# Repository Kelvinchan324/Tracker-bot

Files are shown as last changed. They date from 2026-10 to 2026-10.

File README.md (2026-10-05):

# Tracker Bot

## EVT-A.1 build and teaching manual (5 October 2026)

The implemented reference build is **XIAO ESP32-S3 Sense + two SG90 servos**
tracking a red marker. It is an untested hardware draft; it does not yet detect
people. The earlier product vision below describes future goals.

[Engineering manual](docs/engineering.md) · [BOM](hardware/BOM.md) ·
[Wiring schematic](hardware/schematic.svg) · [Placement drawing](mechanical/placement.svg) ·
[STEP draft](mechanical/layout-draft.step)

**Wiring revision:** EVT-A.1 uses TXU0102, not the old AHCT125. Read the
[power-cut and interlock guide](docs/power-and-interlock.md) and
[parametric mounting drafts](mechanical/README.md). Do not reuse the old pinout.

1. Read the wiring and power notes. Keep the camera USB and motor supplies separate;
   join ground. Wire GPIO1/D0 and GPIO2/D1 through the translator, GPIO3 to OE,
   and GPIO4 to the separate NC stop contact with its 3.3 V pull-up.
2. Install PlatformIO and run `cd firmware`, then `pio run -e xiao-sense`.
3. With horns removed and motor power off, connect USB and run
   `pio run -e xiao-sense --target upload`, then `pio device monitor`.
4. Boot should report motors DISARMED. Verify no PWM. Enable motor power, support
   the mechanism, close the stop contact, then enter `arm`; the last commanded
   position (initially centre) can cause movement. Release after a stop does not re-arm.
5. Try `target 0.2 0` in serial mode. Check direction and timeout before fitting
   the horns. `stop` holds position; `disarm` removes PWM. Use the physical cut if needed.
6. Enter `camera` and present one red marker. Remove it to check lost-target behaviour.
   Enter `serial` to return to manual target input. Use `status` for diagnostics.
7. Follow the four lessons in the engineering manual and save the measured results.

Read the [camera freshness and calibration lesson](docs/camera-calibration.md)
before marker tracking. Frame age is measured from capture start, not retrieval.
`status` reports the last frame classification, red sample/candidate/selected
counts and capture age. Two separate qualifying red regions now reject as
`ambiguous`; a unique region needs at least 20 connected samples. Touching objects
can still merge, and a lone distractor can still qualify—this is not identity tracking.
Fresh images without a unique marker stop incremental commands but hold PWM;
normal marker reacquisition remains automatic while camera mode is selected.
Camera-stream faults (missing/invalid/stale frames or age over 750 ms) now exit
camera mode. Fresh frames alone cannot restart it: inspect the fault, wait for
`camera_stream=live`, then send `camera` explicitly. This main-loop check is not
an independent watchdog or power cut. No encoder or obstruction sensor is
implemented, and physical stopping remains unvalidated.

Serial control now rejects malformed or unknown commands by stopping tracking
and leaving camera mode. Lines are limited to 96 ASCII bytes and must finish
within one second of their first processed byte. Rejected lines are discarded
through the next newline. Read the [serial controls lesson](docs/serial-controls.md)
before attaching scripts; stopping increments still holds PWM, not motor power.

PWM setup now uses the ESP32-S3's supported **14-bit, 50 Hz** configuration.
The earlier 16-bit request was rejected by the pinned driver despite compiling.
Both axes must report successful setup before `arm`; `status` includes `pwm_setup`.
Read the [PWM startup lesson](docs/pwm-startup.md) and measure the actual outputs
with motors unplugged. A successful driver return does not verify a waveform.

The CAD now includes [candidate moving carriers and joint-frame review](mechanical/carrier-review.md),
with a [labelled STEP-derived assembly review](mechanical/carrier-visual-review.png)
showing assumed actuator axes, camera envelope and unfinished horn connections,
not a finished pan/tilt mechanism. Run `python tools/build_engineering.py --cad`,
`python tools/build_mounts.py`, then `python tools/build_carriers.py` with CadQuery
2.8.0. The last script samples 25 nominal poses and reports envelope intrusion;
it does not certify continuous clearance or measured shaft/optical frames.
Actual motor travel, bracket fit, camera orientation, back-feed,
continuous current and tracking quality remain physical acceptance tests.

A compact, affordable pan-and-tilt camera that follows a selected person or
object using on-device computer vision.

Tracker Bot takes the core idea behind the larger
[YOLO Tracker](https://github.com/Kelvinchan324/YOLO_tracker) and explores how
to turn it into a smaller, quieter, lower-cost product for individual
customers. The proposed design uses an AI-capable ESP32 module for lightweight
tracking and two compact actuators for yaw and pitch.

> **Project status:** early product concept and feasibility study. The camera,
> ESP32 module, actuators, power system, enclosure, and retail specifications
> have not been finalized.

## Product vision

- Small enough for a desk, shelf, tripod, or portable demonstration setup.
- Lower-cost alternative to a Raspberry Pi and full-size smart-servo tracker.
- On-device tracking with low latency and no mandatory cloud connection.
- Simple setup for non-technical B2C customers.
- Smooth, quiet motion suitable for home video, calls, content creation, and
  hobby use.
- Modular mechanical design so the actuator choice can change without a full
  enclosure redesign.

## Proposed system

```mermaid
flowchart LR
    Camera[Camera sensor] --> ESP[ESP32 edge-AI module]
    ESP --> Detect[Lightweight person or object detector]
    Detect --> Control[Target selection and motion controller]
    Control --> Yaw[Yaw actuator]
    Control --> Pitch[Pitch actuator]
    Limits[Calibration, travel limits and fail-safe] --> Control
    Power[Power and motor drivers] --> ESP
    Power --> Yaw
    Power --> Pitch
```

The intended vision loop is:

1. Capture a low-resolution frame.
2. Run a compact, quantized detection or tracking model on the ESP32.
3. Select a target and calculate its offset from the image center.
4. Apply a deadband and a tuned proportional or PID controller.
5. Command the yaw and pitch actuators within calibrated travel limits.
6. Stop safely when the target is lost, the mechanism is obstructed, or a
   hardware fault is detected.

## Actuator direction

Two candidate products are being considered:

| Candidate | Link | Current status |
| --- | --- | --- |
| A | [Taobao item 611225445203](https://item.taobao.com/item.htm?id=611225445203) | Specifications and compatibility not yet verified |
| B | [Taobao item 1014228956726](https://item.taobao.com/item.htm?id=1014228956726) | Specifications and compatibility not yet verified |

These links are research candidates, not approved parts. Their listings,
prices, availability, specifications, and seller claims can change.

### Small servo motor

Advantages:

- Integrated gearbox and position control can simplify the electronics.
- Easier firmware integration and faster proof-of-concept development.
- Usually cheaper and easier to replace.

Risks to evaluate:

- Gear noise, backlash, vibration, and visible stepping.
- Limited life under continuous tracking motion.
- Motion may not be smooth enough for video.

### Gimbal motor

Advantages:

- Potentially smoother and quieter motion.
- Low backlash and better motion quality for camera applications.

Risks to evaluate:

- Requires a compatible motor driver and control method such as FOC.
- May require an encoder or other position feedback.
- More tuning, electronics, firmware, and calibration effort.
- Total system cost may exceed the cost of the motor itself.

### Required actuator validation

Do not commit the mechanical design until both candidates have been checked
for:

- operating and peak voltage;
- stall, rated, and continuous torque;
- control interface and compatible driver;
- absolute or incremental position feedback;
- speed, response time, and control resolution;
- shaft, mounting-hole, and body dimensions;
- cable and connector requirements;
- current draw, heat, and safe duty cycle;
- acoustic noise, backlash, and vibration;
- repeatability after power cycling;
- unit cost at prototype and production quantities;
- supplier consistency, lead time, and replacement availability.

## ESP32 edge tracking

The exact ESP32 module and camera are still to be selected. The target
implementation should favor:

- an ESP32 variant with enough memory and acceleration for a small vision
  model;
- a camera interface supported by the selected module;
- a small input size and an INT8-quantized model;
- person, face, or single-object tracking rather than a large general-purpose
  detector;
- frame skipping and region-of-interest tracking to reduce compute load;
- motor updates at a stable rate independent of camera inference timing;
- local processing by default, with no required image upload.

The first benchmark should measure detection accuracy, end-to-end latency,
frame rate, memory use, temperature, and power consumption on the actual
ESP32 hardware. Model choice should follow those measurements rather than the
model name alone.

## Product requirements

### Customer experience

- One-button startup and automatic center calibration.
- Clear power, tracking, and privacy indicators.
- Simple target selection and an easy way to pause tracking.
- Stable behavior when the target leaves or re-enters the frame.
- USB-powered operation if the selected motors allow it; otherwise use one
  clearly labeled external supply.
- Replaceable cable and modular actuator assembly.

### Safety and privacy

- Mechanical travel limits and software position limits on both axes.
- Current limiting or stall detection to protect fingers, gears, and motors.
- Controlled startup with no sudden movement.
- Stop motion on camera, feedback, communication, or thermal failure.
- Pinch-point guards and a stable, tip-resistant base.
- On-device processing and no cloud upload by default.
- Visible indication whenever the camera or tracking function is active.
- Secure firmware updates and no undocumented network services.

### B2C readiness

Before sale, the design will need:

- a repeatable bill of materials and at least one backup supplier for critical
  parts;
- design-for-assembly and production test procedures;
- enclosure durability, drop, cable-strain, thermal, and long-duration motion
  tests;
- electrical, battery, radio, and product-safety compliance appropriate to
  every sales region;
- privacy documentation, firmware-update policy, warranty, and support plan;
- manufacturing cost, packaging, fulfillment, returns, and retail margin
  validation;
- freedom-to-operate and software/model licensing review.

## Development roadmap

- [ ] Confirm the first customer use case and target retail price.
- [ ] Buy and bench-test both actuator candidates.
- [ ] Select the ESP32 module, camera, motor drivers, and power architecture.
- [ ] Benchmark a lightweight tracking model on the selected ESP32.
- [ ] Build a two-axis electronics prototype with no camera payload.
- [ ] Establish travel limits, lost-target behavior, and stall protection.
- [ ] Design and print the first compact mechanical prototype.
- [ ] Tune tracking, motion smoothing, and acoustic performance.
- [ ] Run thermal, endurance, drop, and cable-strain tests.
- [ ] Build a small pilot batch and collect customer feedback.
- [ ] Freeze the product specification only after pilot validation.

## Firmware quick start

The repository now includes a basic ESP32-S3 PlatformIO project in
[`firmware/`](firmware/). It can move two PWM hobby servos, receive simulated
target coordinates through the serial monitor, enforce configured travel
limits, and stop issuing incremental targets when updates are lost. Holding a
commanded position is not a verified physical stop.

Open the `firmware` folder as a PlatformIO project in VS Code. See the
[`firmware/README.md`](firmware/README.md) for wiring, commands, and safety
notes. Camera inference and brushless-gimbal support will be added after the
exact hardware has been selected.

## Planned repository structure

```text
Tracker-bot/
|-- firmware/       # ESP32 camera, inference, control and communications
|-- hardware/       # Schematics, PCB files and bill of materials
|-- mechanical/     # CAD, drawings and printable prototypes
|-- models/         # Model metadata and conversion instructions
|-- tests/          # Bench, endurance and production tests
`-- docs/           # Product requirements, decisions and user documentation
```

## Open decisions

- Which customer scenario comes first: video calls, content creation,
  education, pets, or general object tracking?
- Is a small servo sufficiently smooth and quiet, or is a closed-loop gimbal
  motor required?
- Which ESP32 and camera combination meets the latency and cost targets?
- Can the product use one USB power input while meeting motor peak current?
- What target size, weight, retail price, and continuous operating life are
  required?
- Which features belong in the first sellable version versus later versions?

## Contributing

This repository is currently a concept workspace. Record measurements,
datasheets, design decisions, and test results alongside every hardware or
software change so future choices remain evidence-based.

## License

No license has been selected yet. Unless a license is added, the repository's
contents should not be assumed to grant permission for reuse or distribution.

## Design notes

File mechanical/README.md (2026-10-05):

# Mechanical drafts: what can and cannot be built

The layout STEP locates electronics and actuators as **bounding envelopes**.
It is not a full moving assembly. Two additional parametric candidates now exist:

- `yaw-seat-draft.step/.stl`: servo body seat, cable relief and slotted mounting feet.
- `camera-saddle-draft.step/.stl`: open-ended board saddle with slotted mounting feet.
- `mounting-drafts.step`: both candidates in the same world coordinates as their
  component envelopes. This earlier file contains the two mounts only; the newer
  [carrier assembly and review](carrier-review.md) adds candidate connecting parts.

Run `python tools/build_mounts.py` from the repository root with CadQuery 2.8.0.
Edit `mount-parameters.json` for walls, fit allowance and slots; component sizes
and positions come from `hardware/rev-a.json`. Do not manually move the exports
without updating the source. `mount-checks.json` records attachment-slot centres
and computational volume/fit checks.

## Interface status

| Interface | Current definition | Gate before fabrication/operation |
| --- | --- | --- |
| M1 yaw body | 23 x 12.2 x 29 mm source envelope; +Z intended shaft direction | Measure ears, cable exit, true shaft offset and clamp fit |
| Servo seat | 0.6 mm per-side allowance, 3 mm walls, 2.5 mm base, 10 mm wall height | Printing tolerance, positive retention and strength tests |
| M2 pitch body | Rotated case envelope; +Y intended shaft direction | Actual mounting ears, horn axis and load path unresolved |
| Camera board | 22 x 18 x 15 mm assumed clearance envelope at (15,0,87) | Exact board/camera stack, antenna, lens and USB access |
| Camera saddle | Open ends, 8 mm walls, slotted feet | Must not contact antenna or block field of view |
| Mount foot slots | 6 mm total length, 3.4 mm width, elongated along Y | Matching holes/backing access, screw length and edge strength |
| Yaw-to-pitch carrier | Candidate deck, risers and pitch seat | Supplied horn attachment, positive retention and measured centres |
| Pitch-to-camera joint | Candidate side plate and camera shelf | Supplied horn attachment, opposite-side bearing/load review |

The yaw seat bottom is at the fixture plate top (4 mm). The camera saddle is
positioned under the camera envelope. In `carrier-layout.step` it rests on a
candidate shelf; horn coupling is still unresolved. `carrier-fixture-plate.step`
adds matching yaw-seat holes; the original fixture plate export remains unchanged.
Do not treat concept connections or zero envelope intrusion as a functioning mechanism.

## Measurement lesson (60 minutes)

1. Record servo body, ears, screw centres, horn plane, shaft offset and cable exit
   in millimetres. Photograph the calliper setup and note uncertainty.
2. Record camera stack, connectors, antenna keepout and optical axis.
3. Update source envelopes and regenerate candidates; compare against measurements.
4. Check fastener insertion, cable bend, pinch points and the entire intended
   yaw/pitch travel. The software angle labels are not measured shaft angles.
5. Obtain a mechanical review before printing load-bearing parts or powering motors.

CAD validation currently checks connected positive-volume solids, STEP re-import
and no penetration into the assumed static component envelope. It does not check
stress, print orientation, inserts, tolerances, moving collisions or fatigue.

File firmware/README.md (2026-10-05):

# Tracker Bot firmware — EVT-A

Experimental two-axis servo firmware with a red-marker camera path.
It has compiled for both boards below; physical operation is not validated.
Read the [engineering build and teaching manual](../docs/engineering.md) before
wiring or uploading. This is not brushless-gimbal firmware or person recognition.

| Environment | Board | Yaw / pitch | Camera |
| --- | --- | --- | --- |
| `xiao-sense` (default) | XIAO ESP32-S3 Sense | GPIO1 / GPIO2 | RGB565 red-marker centroid |
| `esp32-s3-devkitc-1` | ESP32-S3 DevKitC-1 | GPIO4 / GPIO5 | Serial targets only |

EVT-A.1 also requires translator OE and the separate NC power-cut auxiliary
contact: XIAO GPIO3/GPIO4 respectively, DevKit GPIO6/GPIO7 respectively.
Open auxiliary contact (or disconnected cable) inhibits arm. Wire the new
TXU0102 from the current schematic, not the obsolete AHCT125 DIP14 circuit.

## Build and upload

Install PlatformIO Core or the PlatformIO extension in VS Code. Open this folder.
Run `pio run` to compile the default board. Only after wiring review, use
`pio run -t upload` and `pio device monitor` (115200 baud).
Choose the other target explicitly with `-e esp32-s3-devkitc-1`.

## Supported bench sequence

Start with horns removed, mechanism restrained, current-limited motor supply
and a reachable physical power cut. USB powers the MCU, not the motors.
Use the buffer and separate regulated motor supply in the
[module schematic](../hardware/schematic.svg); do not connect motors to 3.3 V.

Send newline-terminated commands:

```text
status
arm
target 0.2 0
stop
center
camera
stop
disarm
```

- Boot is disarmed; `arm` applies the last commanded position (initially centre).
  A closed auxiliary contact is required. Opening it disarms; reclosing it alone
  does not restart motion. An external motor-rail loss without contact opening
  is not detected: disarm before reconnecting power.
- `target x y` accepts finite values in [-1,1], in armed serial mode only.
  Negative x/y means left/up. Actual installed directions need a hardware check.
- Commands are case-insensitive ASCII words, with exactly their documented
  arguments. Decimal/scientific numbers are accepted; NaN, infinity, hexadecimal,
  comma decimals and trailing tokens are rejected. A malformed/unknown command
  stops increments and exits camera mode, while holding the last PWM.
- Target commands in the wrong mode are rejected and stop tracking/leave camera
  mode; they never arm implicitly. Select the mode deliberately before retrying.
- Maximum line length is 96 bytes excluding CR/LF; send the complete line within
  one second. Oversized, non-text or expired partial lines are discarded through
  the next CR/LF. Send a newline followed by a fresh command to recover.
- Targets expire after 750 ms; the last pulse is held. There is no encoder feedback.
- Camera targets retain the capture-start timestamp. Only complete 160x120
  RGB565 frames with valid, nonfuture timestamps within 750 ms are processed;
  queue/processing time does not refresh their age. Controller input also rejects
  stale/future timestamps. At the exact 750 ms boundary a target is still eligible.
- `camera` enables marker input only after capture initialized AND a valid image
  is currently fresh (`camera_stream=live`). It does not arm motors.
- Exactly one four-connected red region with at least 20 sampled pixels is
  required. Multiple qualifying regions report `ambiguous`; disconnected smaller
  speckles are excluded from the centroid. Touching objects/red bridges can merge;
  no identity lock, shape test or upper-area rejection is implemented.
- Fresh no-marker/ambiguous images stop increments but retain camera mode; a
  subsequent unique marker can resume tracking automatically.
- Missing/invalid/stale frame results or capture age over 750 ms stop increments
  AND exit camera mode. Fresh images alone do not resume motion after this fault:
  inspect the issue, wait for `camera_stream=live`, then explicitly send `camera`.
  Arming is unchanged and the last PWM stays held; this is not power isolation.
- `serial`, `stop` and `center` leave camera tracking; `center` needs arming.
- `disarm` removes PWM but is not a physical power cut; support the payload.
- `status` reports arming, input mode, camera state, commanded angles and target.
- `camera_stream` reports waiting/live/no-frame/invalid-frame/stale-frame/timed-out,
  or unavailable when capture did not initialize. Freshness uses capture time,
  not queue receipt. `last_frame` is historical; a hung task can leave an old
  `marker` label while the stream is timed-out. A running main loop is required
  to detect this; no independent task/MCU watchdog or restart is implemented.
- `red_samples` counts every-other-row/column samples, not area.
- Pins, ranges, deadband and gain are in `include/app_config.h`.

Use [host logic tests](../tests/README.md) and compile both environments after
changes. Neither compilation nor mocked tests proves electrical or mechanical safety.

Complete the [camera identification, polarity and latency worksheet](../docs/camera-calibration.md).
The [serial lesson](../docs/serial-controls.md) includes grammar, failure behavior
and a motors-disconnected test sequence. A software input check is not an E-stop.

### PWM initialization gate

Both supported builds use 14-bit LEDC at 50 Hz. ESP32-S3 does not support the
previous 16-bit setting. Each axis checks the pinned driver's returned frequency;
zero or any result other than 50 Hz inhibits arming of both axes. Startup prints
a failure message and `status` reports `pwm_setup=FAILED`; there is no serial
retry command. Inspect the configuration and restart deliberately with motor
power isolated. `pwm_setup=ready` means driver setup passed, not scope verification.
See [PWM startup tests and lesson](../docs/pwm-startup.md).

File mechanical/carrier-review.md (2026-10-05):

# Candidate carriers and frame convention

These parts explore a load path. They are **not approved for fabrication or motor
operation**. Actual supplied horn attachments, retention and bearing loads remain
unresolved; no spline, horn screw pattern or motor shaft offset is invented.

## Editable files

- [Parameters](carrier-parameters.json); [sampled pose report](carrier-checks.json).
- [Yaw carrier STEP](yaw-carrier-draft.step) / [STL](yaw-carrier-draft.stl).
- [Pitch carrier STEP](pitch-carrier-draft.step) / [STL](pitch-carrier-draft.stl).
- [Revised fixture STEP](carrier-fixture-plate.step) / [STL](carrier-fixture-plate.stl).
- [Eleven-solid assembly STEP](carrier-layout.step), including component envelopes.

Generate in order with CadQuery 2.8.0:

```sh
python tools/build_engineering.py --cad
python tools/build_mounts.py
python tools/build_carriers.py
python -m unittest discover -s tests -p test_frames.py
```

The yaw deck is above M1, joined by two risers to M2's seat. The seat's +Y wall
is open toward the assumed horn side. The pitch plate is outside that case face,
with an upright and shelf under the existing camera saddle. Horn lands are
deliberately undrilled. This is not a rigid connection to either servo output.

The carrier fixture adds two 3.4 mm yaw-seat holes at X=±18.1, Y=0 mm to the
original plate. Camera shelf holes align to the saddle slots at X=-2.6 and 32.6,
Y=0 mm. Determine screw lengths, nut/tool access and anti-loosening from actual
parts. No hole pattern is added to the servo body or camera electronics.

## Frames — assumptions, not calibration

World frame is the plate centre in XY, plate bottom Z=0, +Z up. Right-handed
positive yaw rotates about +Z; positive pitch rotates about local +Y. The pitch
frame travels with the yaw carrier. Point math applies local pitch first, then
world yaw. All lengths are millimetres, all planning angles degrees.

| Reference | Zero-pose origin | Direction / interpretation |
| --- | --- | --- |
| Yaw joint | (0,0,37) | +Z; assumed shaft line |
| Pitch joint in yaw-zero frame | (0,18,60) | +Y; assumed shaft line |
| Camera envelope centre | (15,0,87) | Bounding-box centre only |
| Camera optical frame | Unknown (`null`) | Must come from board/lens measurements and calibration |

The manufacturer's [SG90 page](https://towerpro.com.tw/product/sg90-analog/)
supports the case dimensions used earlier, but not these assumed shaft origins.
No claim is made that 90-degree software commands mechanically zero either axis.
Actual sign, gain, pulse mapping and end stops must be calibrated with horns
removed before supported assembly testing. Do not widen firmware limits from CAD.

## Sampled motion review

The generator reads current firmware min/centre/max commands and requires sample
endpoints matching their offsets: yaw ±30, pitch ±20 at this revision. It samples
five values per axis (25 poses), testing moving candidate solids and component
boxes against each other and fixed boxes, yaw seat and fixture. Intended contact
surfaces are allowed; positive-volume intrusions above 1e-5 mm3 are reported and
make the script fail after writing the report.

The current 25 samples have no detected intrusion. This is **not continuous
collision clearance**: gaps can be zero, boxes omit ears/horns/fasteners, and
wires/USB cables, tolerances, deflection and fingers are not modeled. Camera-frame
math is checked independently against the CAD-transformed envelope centre.
No camera viewing ray or sensor protection zone is claimed.

## Teaching / measurement worksheet

1. Identify fixed, yaw-moving and pitch-moving bodies in the STEP assembly.
2. Predict the pitch-axis direction after +30 degrees yaw; compare the report.
3. Explain why replacing a camera-envelope centre with an optical centre is wrong.
4. With power removed, measure actual servo shaft offsets/horn planes and camera
   interfaces. Record uncertainty and the exact part revision.
5. Update parameters, inspect all sample intrusions, then perform a separate
   continuous swept-volume and wire-routing review. Do not suppress failures.

| Gate | Evidence |
| --- | --- |
| Actual yaw/pitch shaft offsets and horn planes | pending |
| Supplied horns, screw engagement, carrier attachment | pending |
| Positive body/board retention and opposite pitch bearing | pending |
| Camera optical pose, antenna and USB keepouts | pending |
| Load, backlash, support deflection and thermal limits | pending |
| Cable sweep, pinch points and full travel clearances | pending |
| Supported physical travel and stop test | pending |

No physical result is inferred from the generated report.

## Visual review and source freshness

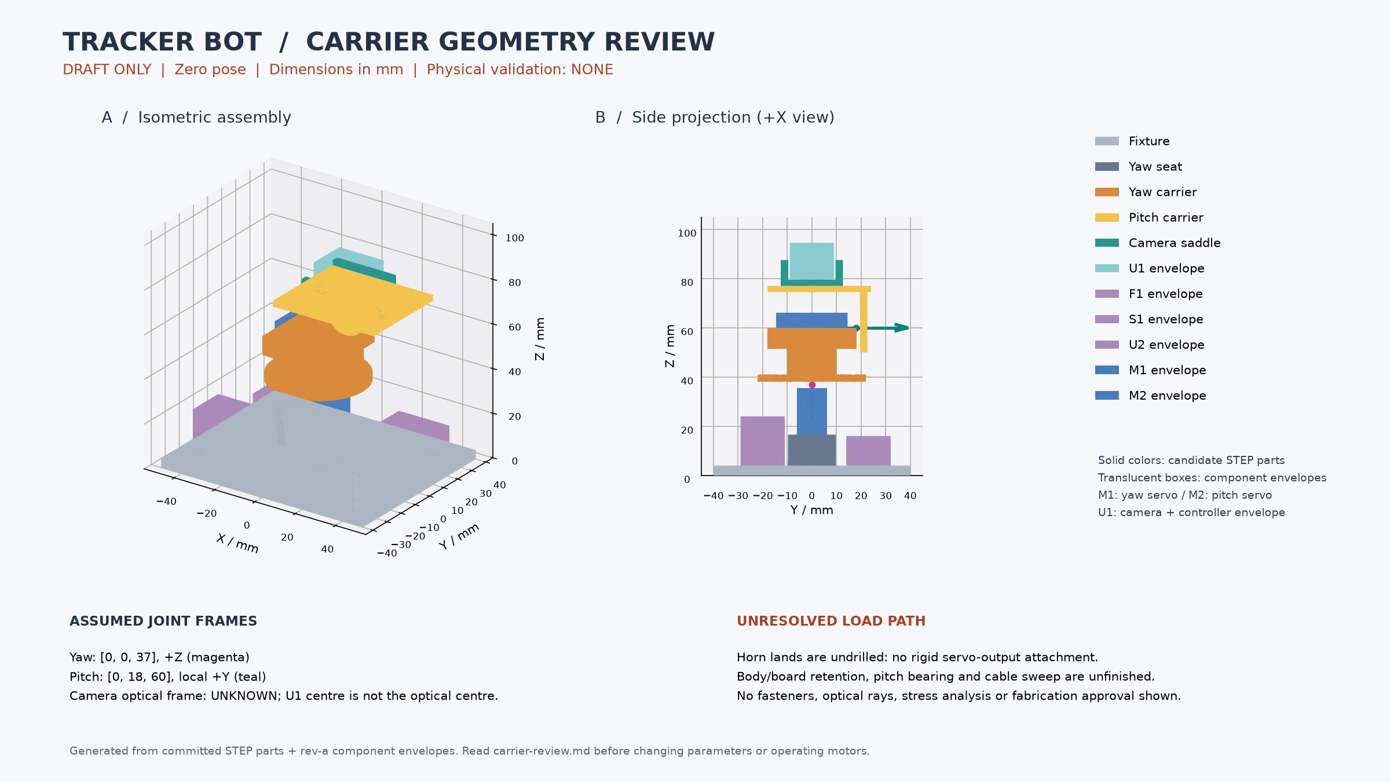
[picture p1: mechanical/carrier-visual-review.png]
Zero-pose carrier review from STEP parts


The [render ledger](carrier-visual-review.json) identifies all 11 bodies and hashes
its input STEP files, component manifest, frame parameters and rendering script.
Candidate solids come from their individual STEP files; component boxes come
from the manifest. Before rendering, each body is matched one-to-one with the
saved assembly by volume (within 1e-4 mm3) and bounds (within 1e-4 mm). Matching
these signatures does not prove topological identity or mechanical fit.

The image has been visually inspected at zero pose. It shows the vertical stack,
camera/controller envelope above the saddle, offset pitch plate and unresolved
horn gaps. It is not a dimensioned manufacturing drawing: tessellation and
translucent-surface depth ordering can obscure faces. Read the editable solids
for geometry; do not measure clearances or hole locations from image pixels.
The yaw axis is partly occluded by the carrier; its magenta origin and the frame
table identify the assumption. No optical ray or actual shaft shape is invented.

Reproduce with CadQuery 2.8.0 and Matplotlib 3.11.2:

```sh
python tools/render_carrier_review.py
python -m unittest discover -s tests -p test_visual_review.py
```

The renderer reads existing geometry and does not modify STEP/STL sources. The
lightweight CI test checks the committed image/ledger are current; it does not
install CAD software or recompute solids. If source hashes change, regenerate
and visually inspect the new image before committing. JSON/Python line endings
are normalized for hashes; STEP/PNG retain native bytes. Renderer versions may
change tessellation or pixels, so keep both the updated image and ledger.

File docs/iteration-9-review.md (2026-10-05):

# Iteration 9 — ESP32-S3 PWM initialization blocker

5 October 2026. No hardware connected or flashed.

Source audit found a runtime blocker missed by previous successful builds: the
firmware requested 16-bit LEDC resolution, while ESP32-S3's capability header
allows at most 14 bits. The pinned driver returns zero on that unsupported
request; the application and its old void-returning native shim ignored it.

Changed to 14-bit/50 Hz with embedded capability assertions. Each axis requires
the driver's expected frequency before it is ready. Either failed axis blocks
arming of both; startup and status expose failure. No automatic retry exists.
Zero duty is set before attaching pins, both pulse targets precede OE high, and
OE goes low before disarm clears PWM. Reinitialization resets command/contact
state. Pulse conversion uses 2^14 period counts and nearest-count rounding.

Verification: all five strict-warning native programs and five Python tests pass.
The new actual-main-loop PWM test injects failed/unexpected setup results, checks
ordering and diagnostics, and sweeps pulse arithmetic independently. Real board
builds both succeed: XIAO Sense RAM 37,508 bytes, flash 331,361 bytes; DevKit RAM
19,200 bytes, flash 293,709 bytes. CI now includes the new native program.

Source references, a teaching exercise and unexecuted scope worksheet are in
[PWM startup](pwm-startup.md). The hardware manifest, pins, CAD, dependency pin,
motion limits and stop power path are unchanged. Physical attach/write success,
timer accuracy, transients, actual servo pulse widths and stop time remain
unverified. This fixes an evidenced software configuration error, not a hardware
acceptance gate. Prior test records remain historical and must not be read as
proof that their 16-bit firmware generated valid PWM.

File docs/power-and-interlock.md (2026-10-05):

# EVT-A.1 electrical review and acceptance worksheet

Status: engineering draft; no measured power-off or motor result exists.
The revision manifest generates the authoritative pin/net drawing and BOM.
The previous AHCT125 DIP14 arrangement is superseded, not pin-compatible.

## Source basis and design decision

TI's [TXU0102 SCES941A](https://www.ti.com/lit/ds/symlink/txu0102.pdf)
specifies independently powered 1.1–5.5 V ports, partial-power-down support,
and high-impedance outputs when either supply is below 100 mV or disconnected.
OE low also disables both outputs. The DCU/VSSOP8 pin table is:
1 B2Y, 2 GND, 3 VCCA, 4 A2, 5 A1, 6 OE, 7 VCCB, 8 B1Y.
This supports the design selection; it does not validate a purchased breakout.

Design interpretation: motor and logic rails can be sequenced separately without
relying on an ordinary buffer's unspecified output behavior during power-down.
Shared ground remains necessary. This is not a galvanic barrier, safe-torque-off
device, or certified emergency-stop architecture.

## Net-level assembly schedule

| Harness / interface | Connections | Construction/check |
| --- | --- | --- |
| Motor source | P1 + -> F1 -> S1 power NC -> MOTOR_4V8 | Insulated rated wire/connectors; external current-limited supply |
| Motor returns | Both servos -> supply GND star | Do not return servo current through MCU or breadboard |
| Logic rail | XIAO 3V3 -> U2 pin 3; common GND -> pin 2 | C3 100 nF directly at pins |
| Translator motor rail | MOTOR_4V8 -> U2 pin 7 | C1 100 nF locally; C2 470 µF near motor connectors |
| Yaw signal | GPIO1 -> A1/5; B1Y/8 -> M1 PWM | R1 10k input pull-down, R4 47k servo-side pull-down |
| Pitch signal | GPIO2 -> A2/4; B2Y/1 -> M2 PWM | R2 10k input pull-down, R5 47k servo-side pull-down |
| Output enable | GPIO3 -> OE/6 | R3 10k to GND, default disabled |
| Stop auxiliary | GPIO4 -> S1 isolated AUX NC -> GND | R6 10k to logic 3.3 V; never connect motor voltage to this pole |
| Motor discharge | MOTOR_4V8 -> R7 1k -> GND | 0.25 W resistor; nominal 23 mW dissipation at 4.8 V |

GPIO numbering above is XIAO only. DevKit uses PWM4/5, OE6, stop7.
Choose S1 with two electrically isolated, mechanically linked NC contacts:
one with suitable DC motor-current interruption rating, the other specified for
low-level signal service. The exact switch, wire gauge and keyed connector model
remain procurement gates. Do not assume a generic two-terminal button suffices.

At nominal values, the disconnected 470 µF capacitor and 1k bleeder have
RC=0.47 s; 4.8 V to 0.1 V takes about 1.82 s with no other load. Stored energy
is about 5.4 mJ. These are calculations, not measured stop time. Component
tolerance and actual loads change the result; rail interruption is not instantaneous.

## Software behavior and limitations

The OE output is held low during startup. Closing the contact permits a deliberate
arm only after both PWM timer setups succeed; opening it disables OE and PWM on
the next control-loop observation. The S3 uses 14-bit/50 Hz PWM. Source review
found that the earlier 16-bit setting was rejected by its driver despite a clean
build. See the [startup correction and waveform worksheet](pwm-startup.md).
Reclosing cannot arm the controller. Serial processing is limited to 128 bytes
per pass to avoid unbounded input processing.

No claim is made about maximum stop latency. A hung MCU cannot be trusted to
sample the auxiliary pole; the separate power pole must interrupt the motor rail.
A welded or bypassed auxiliary contact cannot be diagnosed by this single channel.
An unrelated loss/return of motor supply is not measured and may restore a prior
command: **disarm and support the mechanism before connecting any supply**.
Boot transients, servo behavior without pulses and pole timing need oscilloscope
and restrained-mechanism tests. A servo can drop its load when torque disappears.

## Required recorded tests

Do the signal tests with motors unplugged first. Record exact component identities,
firmware commit, instruments, wiring photographs and measured waveforms.

| Condition / exercise | Intended behavior | Actual evidence |
| --- | --- | --- |
| USB only, motor supply off | No sustained servo-output drive/back-fed motor rail | Not tested |
| Motor only, USB off | Outputs unpowered/high impedance, servo-side pull-downs active | Not tested |
| Both supplies, boot | OE low; no command until arm and contact closed | Not tested |
| PWM setup failure | Both axes remain disarmed; OE low; status reports failure | Host fault injection passed; real waveform not tested |
| Aux disconnected at boot | Arm refused | Not tested |
| Arm, then press stop | Power pole opens; software disarms on observed open aux | Not tested |
| Release stop | Still disarmed until a new deliberate arm | Not tested |
| Continuous serial traffic | Stop still sampled; record latency | Not tested |
| Rail discharge after cut | Measure curve; compare with nominal RC estimate | Not tested |
| Restart with supported mechanism | No unexpected resumed camera target | Not tested |
| Restrained motors, worst allowed load | Current, temperature, travel and stop behavior recorded | Not tested |

Do not call the electrical design finished until every relevant state has actual
evidence and an independent wiring/mechanical review.

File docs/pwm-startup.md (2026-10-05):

# PWM startup correction and no-hardware lesson

Status: software/source-verified correction; **no measured servo waveform**.

## Why this was necessary

Both board configurations target ESP32-S3. Its pinned SDK capability header
declares eight LEDC channels and a maximum 14-bit timer width. The older Tracker
setting requested 16 bits. Arduino's setup implementation returns zero for an
unsupported width, but Tracker ignored that result. Compilation and the earlier
host shim therefore passed without establishing that PWM could initialize.

Primary sources reviewed:

- [ESP-IDF v4.4.7 ESP32-S3 LEDC capability header](https://github.com/espressif/esp-idf/blob/v4.4.7/components/soc/esp32s3/include/soc/ledc_caps.h).
- [Arduino-ESP32 2.0.17 LEDC implementation](https://github.com/espressif/arduino-esp32/blob/2.0.17/cores/esp32/esp32-hal-ledc.c): setup returns frequency or zero; attach inherits channel duty; attach/write do not return an application-checkable success result.

The locally pinned PlatformIO package is
`framework-arduinoespressif32 3.20017.241212+sha.dcc1105b`; its reviewed
`cores/esp32/esp32-hal-ledc.c` SHA-256 is
`4069ddc26b5ef35b35dd8e37977d20d31e7a13387839b9c7c9dc365f583b23c7`.
No dependency upgrade was made.

## Corrected behavior

1. Hold translator OE low before initializing either axis. Reset tracking,
   arming and the remembered contact observation during initialization.
2. Request 50 Hz with 14-bit resolution. Embedded compile-time checks reject a
   resolution/channel outside the chip's declared capabilities.
3. Require a returned frequency of exactly 50 Hz for each axis. On failure,
   do not attach that axis; neither axis may arm. This is a deliberately strict
   software result check, not a measurement of the clock.
4. Write zero duty before attaching each successful axis's pin. Explicit `arm`
   still requires a closed stop auxiliary contact. Program both stored pulse
   targets before raising OE. Disarm lowers OE before clearing pulse duty.
5. Report `pwm_setup=ready` or `pwm_setup=FAILED` in `status`. Failure is retained
   until deliberate reinitialization/restart; repeatedly sending `arm` does not
   retry setup or override it. Support the mechanism and isolate motor power first.

No pin/net, servo travel limit, target gain or camera timer assignment changed.
Servo channels 0/1 share timer 0; camera XCLK remains channel 7/timer 3. The gate
does not detect a later timer reconfiguration, disconnected signal wire, wrong
pin routing, failed `ledcAttachPin`/`ledcWrite` or bad physical output.

## Pulse arithmetic, not measurement

At nominal 50 Hz the period is 20,000 microseconds. A 14-bit period has 16,384
counts, or about 1.220703 microseconds per count. Duty conversion now rounds to
the nearest count using that full period count, rather than scaling by 16,383
and truncating. The 90-degree software command maps to 1,500 microseconds,
rounded to count 1,229 (nominal 1,500.244 microseconds). Quantization alone is at
most about 0.610352 microseconds; oscillator error and real hardware jitter are
not included. Commanded degrees still do not prove a measured servo angle.

## Teaching exercise (30 minutes, no motors)

1. Build and run `test_pwm_init.cpp` using [the test instructions](../tests/README.md).
2. Predict the result when yaw setup returns zero but pitch succeeds. Verify
   that a closed contact and repeated `arm` cannot raise OE.
3. Repeat for the pitch axis and unexpected nonzero frequency results. Explain
   why “nonzero” alone would not validate the pulse conversion assumptions.
4. Trace the host-recorded output order for successful startup, arm and disarm.
   Distinguish call ordering from electrical propagation or stop latency.
5. Calculate the nominal centre pulse independently. Explain why a clean compile,
   a successful driver return and a physical waveform are three different kinds
   of evidence.

The host test uses a scripted S3-like shim, not the actual peripheral. The board
builds compile against real capability headers; neither build is hardware execution.

## Physical acceptance worksheet — NOT EXECUTED

Begin with motors unplugged and the power-cut path independently reviewed.
Record board/firmware identity, scope model, probes, ground arrangement and rails.

| Check | Required evidence |
| --- | --- |
| USB boot and camera startup, no arm | OE stays low; record both MCU and servo-side signal traces |
| Closed contact plus explicit arm | Measure frequency, pulse widths and first-pulse behavior on both outputs |
| Minimum/centre/maximum allowed commands | Measure commanded pulse range and jitter; do not infer shaft angle |
| Open auxiliary contact/disarm | Measure OE and output timing; compare separately with physical power cut |
| Power sequencing and reset | Record transients and back-feed checks from the electrical worksheet |
| Supported mechanism, no payload | Only after electrical approval: verify directions, travel and stopping |

All physical rows remain pending. No waveform, independent watchdog, torque-off,
balance or gravity-support guarantee is created by this firmware change.

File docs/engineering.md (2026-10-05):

# Tracker Bot EVT-A engineering draft

Revision A.1 chooses a small, wired desk demonstrator: XIAO ESP32-S3 Sense,
two SG90 hobby servos, a separate regulated 4.8 V motor supply and a bright red
marker. It implements an experimental camera-to-motion path; person recognition, quiet
gimbal actuation, battery operation and a consumer enclosure remain future work.

## Controlled files

- [Electrical schematic](../hardware/schematic.svg): labelled module pins and nets.
- [BOM and net list](../hardware/BOM.md): quantities, source and unresolved selection.
- [Revision source](../hardware/rev-a.json): editable electrical/mechanical assumptions.
- [Placement drawing](../mechanical/placement.svg) and [STEP layout](../mechanical/layout-draft.step).
- [Fixture STEP](../mechanical/fixture-plate.step) and [STL](../mechanical/fixture-plate.stl).
- [CAD/document generator](../tools/build_engineering.py).

The STEP assembly contains labelled component bounding boxes and a drilled fixture
plate. It is a packaging study, not accurate servo internals, a finished pan/tilt
mechanism or print-approved parts. Hole locations on the plate are for fixture
attachment only. Horn centres, spline, screws and moving brackets are not released.
Two [parametric mounting candidates](../mechanical/README.md) add a yaw-body
seat and camera saddle. They do not yet connect through a rotating carrier.

## Electrical rationale

The camera board receives USB power. A separate 4.8 V supply feeds F1, then the
latching NC power-cut contact S1, then both servos and the buffer. Grounds join
at the motor connector. Never route servo supply current through XIAO pins,
USB ground jumpers or solderless breadboard contacts. Use short adequately rated
power leads, keyed connectors, strain relief and insulated terminations.

U2 is now a TXU0102 dual-supply translator, not the previous AHCT125.
VCCA receives MCU 3.3 V and VCCB receives switched motor power; grounds are common.
The [power and interlock review](power-and-interlock.md) gives the IC pin mapping,
pull resistors, two-rail bypass capacitors, wiring schedule and power-state tests.
Do not reuse the previous DIP14 wiring. The new part is VSSOP8 and needs a
verified breakout. This is signal isolation on power-off, not galvanic isolation.
Hardware back-feed, timing and fault tests remain mandatory.

Source facts: [Seeed pin map](https://wiki.seeedstudio.com/xiao_esp32s3_getting_started/),
[Seeed camera guide](https://wiki.seeedstudio.com/xiao_esp32s3_camera_usage/),
[TowerPro SG90](https://towerpro.com.tw/product/sg90-analog/),
[TI TXU0102](https://www.ti.com/lit/ds/symlink/txu0102.pdf). Accessed 5 October 2026.
Supplier listings and measured samples must settle signal thresholds, current
peaks and actuator travel. F1=2 A is a starting engineering assumption, not a
validated protection coordination result.

## Mechanics and placement

Coordinates are millimetres: origin at plate XY centre and bench height Z=0;
+X is forward, +Y left, +Z up. M1 is the yaw motor, shaft along +Z.
M2 is the pitch motor, shaft along +Y. The camera lens should face +X;
its electronics envelope is centred at (15,0,87). Keep its antenna free of
metal and keep wires outside the two swept volumes.

The 100 x 80 x 4 mm base has four 3.4 mm fixture holes at (+/-43,+/-33).
A 23 x 12.2 x 29 mm servo body envelope comes from the manufacturer;
horn and mounting-ear dimensions need measurement. Put a bearing opposite the
pitch servo if payload or bracket flex requires it. Do not load the servo shaft
as the sole cantilever support without a load check.

Sizing example, not a tested payload: a 50 g camera assembly with centre of
mass 20 mm from pitch axis gives 0.05 x 9.81 x 0.02 = 0.00981 Nm static torque.
Cable drag, acceleration, backlash and continuous duty add load. Published stall
torque is not a continuous operating rating. Record actual payload mass, offset,
steady current, stall response and temperature before increasing it.

## Software behaviour

Default environment `xiao-sense` pins the ESP32 platform to 6.10.0.
Camera runs in a separate task and communicates via a one-entry queue; the
control loop uses the newest observation. Camera XCLK uses LEDC timer 3/channel 7;
servo PWM uses channels 0/1. No network service or cloud processing is started.

Boot produces no PWM until `arm`. Arming applies the current stored position
(initially 90 degrees), so support the mechanism and fit horns at centre first.
`stop` stops tracking and holds the last PWM; `disarm` removes pulses, which
may let a payload fall. S1 physically interrupts motor power.
Its separate NC auxiliary contact to ground is monitored on GPIO4 (XIAO) or
GPIO7 (DevKit). An open contact/wire disarms and disables translator OE. Releasing
S1 does not re-arm; a new `arm` command is required. This loop-polled input is not
a certified or hardware-latched safety interlock.
Neither is a certified emergency-stop function.

Targets outside [-1,1], nonfinite values, trailing text and overflowing lines are
rejected. Lost or stale targets stop incremental motion after 750 ms.
Control step duration is capped at 40 ms to prevent catch-up jumps.
Default nominal software ranges are yaw 60–120, pitch 70–110 degrees, with
1000–2000 microsecond mapping. They are command coordinates, not encoder readings.

Marker mode thresholds red pixels in 160 x 120 RGB565 frames. It is sensitive to
lighting and background objects. Exactly one four-connected red region of at
least 20 samples is required; multiple qualifying regions reject as ambiguous.
Touching objects may merge and a lone distractor may qualify; no identity lock.
Verify byte order, sensor orientation and motor polarity on the actual camera;
OV2640 and OV3660 board revisions require separate checks.

The [camera calibration lesson](camera-calibration.md) specifies frame metadata,
capture-age checks and the unfilled bench worksheet. Expiry is measured from
capture start, including queue time; it is not renewed when a frame is retrieved.
Fresh no-marker/ambiguous images permit ordinary automatic reacquisition while
camera mode remains selected. Invalid/missing/stale frames or a capture age over
750 ms now exit camera mode and hold PWM. After recovery, `camera_stream=live`
and an explicit `camera` command are required to select marker input again.
This is not person identity tracking or an independently supervised stop.

## Teaching sequence and acceptance evidence

1. **Electronics (45 min):** with motors disconnected, identify all schematic
   nets using continuity checks. Measure regulated rails and PWM with a scope.
   Evidence: annotated schematic, measured rail values, centre pulse and power-cut result.
2. **Control (45 min):** horns removed; upload, confirm no startup pulse, arm,
   send `target 0.2 0`, then stop. Evidence: bounded direction, timeout,
   NaN/range rejection and power-cycle transcript. Reverse one axis in code if needed.
3. **Vision (60 min):** put a red card in a plain background; run `camera`.
   Evidence: marker centring, loss, distractor and re-entry clips under two lighting conditions.
4. **Mechanical review (45 min):** measure the actual parts and revise envelopes.
   Evidence: calliper table, cable sweep, finger clearance and stable-base test.

The product draft is not finished until brackets/horn connections, current limits,
sensor orientation, endurance and the user's desired target class have evidence.

The [candidate carrier/frame lesson](../mechanical/carrier-review.md) now adds
editable connecting solids, revised plate holes and 25 sampled pose checks. It
does not replace the physical mechanical review or increase the commanded travel.

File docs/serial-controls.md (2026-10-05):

# Serial controls and input-failure lesson

Revision: 5 October 2026. Development firmware, not a safety-rated controller.
These behaviors have native software tests and embedded compile evidence, not
physical servo, USB timing or stopping measurements.

## Protocol

Use the 115200-baud serial monitor with newline termination. Commands are ASCII,
case-insensitive, and separated from arguments by spaces or tabs. A line has at
most 96 bytes before CR/LF. CRLF is one effective terminator, not two commands.
Empty lines do nothing. Complete a line within 1,000 ms of its first byte being
processed; the exact boundary is allowed, longer delays are rejected. Send whole
lines from the serial monitor rather than slowly typing raw terminal characters.

| Command | Meaning and preconditions |
| --- | --- |
| `arm` | Closed auxiliary stop contact required; applies stored position and may move abruptly |
| `disarm` | Exit camera mode; disable PWM/OE; payload can fall; does not physically isolate power |
| `camera` | Select initialized red-marker input only with `camera_stream=live`; does not arm |
| `serial` | Exit camera tracking and stop increments |
| `target x y` | Exactly two finite decimal/scientific numbers in [-1,1]; armed serial mode only |
| `center` | Exit camera mode and command center when armed; not a gradual trajectory |
| `stop` | Exit camera mode and stop new increments, holding the last PWM |
| `status` / `help` | Read-only command handling; do not renew target lifetime |

Examples: `target .2 -1e-1` and `TARGET 0.2 -0.1` are valid equivalents.
`target0 0`, `target nan 0`, `target 0x1p-1 0`, `target 0,2 0`, `arm extra`
and `target 0 0 extra` are invalid. Values are parsed as numbers and converted
to controller floats; this is not an exact decimal or precision-motion protocol.

## What changed

Previously a malformed target printed an error but left the previous target
eligible until its normal timeout. The new parser and command dispatcher stop
tracking on any unknown/malformed nonempty command, and leave camera mode so a
camera frame cannot immediately restart motion. The arming state and last PWM
are retained. If a valid target is sent while disarmed or in camera mode, it is
rejected and tracking stops; select the intended mode and retry deliberately.

Invalid control bytes (including embedded NUL), non-ASCII bytes and an oversized
line are rejected as soon as processed. An incomplete line expires after one
second, even when no further bytes arrive, provided the foreground loop runs.
The rest of a rejected line is discarded through the next terminator: a suffix
such as `arm` is never interpreted as a replacement command from that same line.
To recover, send a newline, then a fresh complete command. Recovery never arms
automatically. A subsequent complete explicit `arm` is still an operator action.

The line buffer uses fixed storage, not a growing Arduino String. The main loop
still consumes at most 128 serial bytes per pass and rechecks the stop contact
at command dispatch. Opening that contact disarms even if the command is only
`status`; closing it alone does not re-arm. These checks depend on a functioning
foreground loop and are not hardware-latched fault supervision.

## Teaching sequence — start with motors disconnected

1. Run the native parser/controller tests from [tests/README.md](../tests/README.md).
   Explain why strict parsing should happen before any arming action.
2. With motor power physically disconnected and the board's normal reviewed
   low-voltage wiring, observe the serial responses to `arm extra`, `target nan 0`
   and `help`. Do not bridge or defeat the physical stop contact for this lesson.
3. In the native test, trace `arm -> target .5 0 -> target nan 0`: tracking ends,
   but PWM remains enabled. Compare `disarm`. Explain why neither state name
   proves a supported mechanism is safe to touch.
4. Trace a 97-byte line followed by `arm` before its newline: the suffix is
   discarded. Trace a partial `ar`, a delay over one second, then `m`: it must not
   produce a complete arm command. Finally send newline and a fresh command.
5. Before physical motion tests, use the existing supported, current-limited,
   no-payload procedure and independently record signal behavior. No powered
   test is required to complete the software lesson.

## Physical worksheet — not executed

| Evidence | Result |
| --- | --- |
| Operator/observer, exact board, firmware commit, monitor/newline setting | pending |
| Physical motor isolation and restraint before input tests | pending |
| Malformed command response and absence of unintended new target | pending |
| 96/97-byte boundary and discarded-suffix transcript | pending |
| Partial-line expiry, recovery and observed latency | pending |
| PWM hold versus PWM disable, measured separately from mechanical motion | pending |
| Stop-contact precedence and no automatic re-arm | pending |
| Sustained serial input, loop latency and input-buffer overflow behavior | pending |

No authentication, sequence numbers or host-origin timestamps are provided.
This is a local educational serial interface, not a network motion-control API.
USB/UART driver overflow, serial-output blocking, electrical glitches and a hung
CPU remain physical/integration review items; the independent power cut is required.

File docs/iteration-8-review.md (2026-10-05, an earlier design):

# Iteration 8 — explicit camera-stream fault recovery

5 October 2026. Firmware/software evidence only; no hardware attached.

Previously target freshness stopped increments during camera silence, but camera
mode remained selected and fresh frames could restart motion automatically.
Boot initialization also counted as camera readiness indefinitely. Added a
main-loop stream monitor that uses the original capture timestamp, not delivery
time, and differentiates ordinary marker loss from unusable image input.

- Initialization without a fresh valid image no longer permits camera selection.
- Fresh no-marker/ambiguous images keep the stream live and stop increments;
  ordinary marker reacquisition remains automatic while camera mode is selected.
- Invalid/stale/no-frame results or capture age over 750 ms stop increments and
  exit camera mode. PWM/arming are retained, so support the mechanism and use the
  independent physical power cut when necessary.
- Fresh frames after the fault update diagnostics only. Inspect the cause, then
  explicitly send `camera` to select the recovered stream; this does not arm.
  A later delivered valid marker is required for renewed tracking (or the fresh
  frame received in the same loop as the explicit command).
- `camera_stream` complements historical `last_frame` diagnostics. A single mode-
  exit message is emitted per fault, not on every loop. Serial targets remain
  independent of camera-stream health.

The new native test includes production `main.cpp`, real controller/servo code,
and scripted serial/camera/time/GPIO boundaries. It tests initial readiness,
exact 750/751 ms freshness, future/old receipt timestamps, silent camera input,
invalid/stale/no-frame results, explicit recovery, normal marker/ambiguity loss,
PWM hold, command ordering, stop contact, disarmed selection and uint32 rollover.
The host shim does not simulate FreeRTOS, electrical drivers or wall-clock timing.
CI now builds and runs this strict-warning C++17 test.

Verification: new main-loop test and existing controller/serial/component tests
pass. Python frame and visual-review checks pass. Both PlatformIO targets compile:
XIAO Sense RAM 37,508 bytes / flash 330,849 bytes; DevKitC RAM 19,200 / flash 293,197.
These sizes are build reports, not free-runtime-heap or stack measurements. New
remote CI result was not yet checked at commit time. No dependency or CAD change.

This is not an independent watchdog. The main loop must continue executing;
blocked serial output, frozen MCU, real queue scheduling, repeated/faulty camera
timestamps and actual stopping latency require separate hardware validation.
No task restart, power removal, encoder feedback or obstacle detection is added.
Held PWM is neither a physical stop nor guaranteed torque behavior. Do not
hot-unplug a powered camera flex cable to test recovery. The teaching manual
provides synthetic fault exercises and retains the unfilled physical worksheet.

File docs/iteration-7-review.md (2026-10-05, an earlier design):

# Iteration 7 — STEP-derived visual mechanical handoff

5 October 2026. Documentation/visualization refinement; no solid or firmware changes.

Added labelled isometric and side views generated from the actual candidate
STEP files and component-envelope manifest. Before drawing, all 11 bodies are
matched one-to-one against carrier-layout.step using volume/bounds signatures.
The renderer refuses a missing/mismatched body set rather than illustrating a
different assembly silently. This signature is not a topological identity proof.

Visual inspection clarified the stacked M1/M2 arrangement, offset pitch plate,
camera saddle and unfinished horn gaps. Corrected overlapping collapsed-depth
axis labels in the initial render. The final graphic names assumed joint frames
and explicitly labels optical calibration, horn attachment, body/board retention,
bearing and cable sweep as unfinished. Occlusion/tessellation can hide details;
use solids, not pixels, to review geometry. No physical fit is claimed.

Verification: renderer passed its 11-body matching gate; PNG visually inspected;
source/image freshness unittest and scoped Ruff pass. Existing geometry was not
regenerated or modified. Ledger records generator versions and source hashes;
CI adds a lightweight freshness check, not a full CAD build. Source text hashes
normalize CRLF to LF for cross-platform checkouts; STEP/PNG use native bytes.

The previous ambiguity-rejection firmware commit a16e333 passed remote Engineering
checks. This new revision's remote CI still requires checking after push. No
board flashed, motor operated or physical measurement acquired.

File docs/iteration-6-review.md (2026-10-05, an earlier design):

# Iteration 6 — reject spatially ambiguous red-marker frames

5 October 2026. Software-tested engineering draft; motors/camera untested.

The old detector pooled every red sample into one centroid. It could aim between
two separate red objects, or accept scattered noise totaling 20 samples. The new
bounded flood fill requires exactly one four-connected region with at least
20 samples on the every-other-row/column grid. Subthreshold disconnected regions
are excluded from the accepted centroid. Multiple candidates produce `ambiguous`,
clear coordinates and use the existing no-target stop-increments path on delivery.
Capture timestamps, arming gates and command limits are unchanged.

The camera owns a 14,400-byte static workspace (4,800 bytes mask + 9,600 bytes
queue), not a large automatic array on the 4,096-byte capture-task stack. Every
sample is enqueued at most once; no recursion/heap allocation. Detector supports
up to 160x120; capture still requires exact QQVGA. New status fields distinguish
all red samples, qualifying candidates and samples in the unique accepted region.

Verification: new strict-warning component test and existing control/camera and
serial tests pass. Cases include separate candidates, unequal candidate sizes,
split subthreshold regions, speckles, diagonal/bridged adjacency, edge coordinates,
odd-size input, 4,800-sample capacity, canaries and workspace reuse. Both embedded
targets compile: XIAO RAM37,492/flash330,477; DevKit RAM19,184/flash292,841.
New test added to engineering CI; remote result must be checked after push.

Important remaining limitations: one connected red background or distractor can
qualify; touching regions merge; no temporal identity selection or upper-area
rejection. Automatic reacquisition still applies. Thresholds, byte order,
latency/heap/stack headroom, mechanical retention and stopping remain physically
unverified. PWM holds last command on rejected frames; this is not a motor power
cut. README and calibration lesson include a motors-disconnected exercise.

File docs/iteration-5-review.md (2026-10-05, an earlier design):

# Iteration 5 — strict serial command boundary

5 October 2026. Software-tested engineering draft; no board flashed or motors run.

Replaced loosely parsed serial text and growing String buffering with a fixed
96-byte line buffer, strict shared parser and testable command dispatcher.
Unknown/malformed commands now stop incremental tracking and leave camera mode;
they cannot silently retain the previous active target. Wrong-mode targets are
explicitly rejected. PWM remains held until disarm or the separate hardware
power cut; no physical safety guarantee is added.

Framing rejects NUL/non-ASCII/overflow immediately, expires partial lines beyond
one second and discards the remainder through CR/LF. Commands accept exact token
counts and case-insensitive words; decimal/scientific values only. Interlock is
rechecked at dispatch. Read-only commands never refresh the target timestamp.

Verification: new native serial/parser/framer tests pass under strict compiler
warnings using production controller and servo sources. Both pinned embedded
targets compile successfully. Existing controller/camera native checks also pass.
The new binary is included in engineering CI; remote result must be
checked after push. No claim of UART/USB scheduling, physical PWM or stop timing.

README and [serial lesson](serial-controls.md) include exact rejection semantics,
recovery sequence and a blank physical worksheet. This closes the prior review's
malformed-target retention item. Remaining: target identity/distractor handling,
measured mechanical retention and cable sweep, supported hardware tests, and
independent fault supervision.

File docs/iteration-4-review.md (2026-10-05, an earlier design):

# Iteration 4 — capture freshness and camera input review

Date: 5 October 2026. Draft only; no hardware connected or flashed.

Corrected a stale-frame bug: camera targets formerly received a fresh timestamp
after retrieval. They now retain the camera's boot-relative capture-start time.
Only complete 160x120 RGB565 frames with valid, nonfuture timestamps within the
configured age limit reach marker processing. The controller independently
rejects stale/future targets at receipt. Queue and processing time do not renew
target lifetime. Conversion handles millisecond rollover and rejects malformed
large timestamp inputs without integer overflow.

Added last-frame classification, red sample count and capture age to `status`.
README, firmware guide and [calibration lesson](camera-calibration.md) distinguish
held PWM from physical stopping, and explicitly describe automatic reacquisition.
The physical camera/polarity/timing worksheet is deliberately unfilled.

## Verification

- Native production controller/servo/marker/frame-boundary tests: PASS, synthetic
  time and image data only. Added metadata, age-limit, future-time, rollover,
  red-count, color rejection and timestamp-preservation cases.
- Both pinned PlatformIO builds (`xiao-sense`, `esp32-s3-devkitc-1`): PASS.
- No camera DMA/scheduling, sensor color ordering, actual motor, physical stop or
  thermal validation. No CAD or electrical interface changes this iteration.
- Existing CI runs the same native test binary and both embedded builds; the
  new remote run must still be checked after push.

## Next engineering gates

1. Measure real sensor format/orientation/timing and actuator polarity before
   powered tracking; verify source timestamp behavior on the exact board.
2. Review serial parser failure semantics: rejected malformed target text still
   leaves the previous valid target eligible until expiry. Add parser-level tests
   before changing that behavior.
3. Add a scoped target selection strategy: current centroid combines red areas
   and does not maintain object identity. Measure distractors before claiming
   stable object tracking.
4. Resolve motor horns, positive component retention, bearing and cable sweep;
   then inspect and physically validate the previously drafted carrier CAD.

Verdict: stronger input boundary and clearer teaching material; not a finished
consumer tracker or independently safe motion system.

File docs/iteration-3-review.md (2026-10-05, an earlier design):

# Iteration 3 — candidate moving carriers and joint frames

2026-10-05. Untested mechanical draft; no motor operation approval.

## Delivered

- Parametric yaw deck/risers/pitch seat and pitch side-plate/camera shelf.
- Revised fixture with yaw-seat attachment holes and camera shelf holes aligned
  to the earlier saddle's slots. Both horn mounting lands remain undrilled.
- Eleven-solid STEP assembly, individual STEP/STL and editable parameter JSON.
- Right-handed yaw/pitch point transforms, explicit unmeasured joint origins,
  unknown optical frame and a recorded 25-pose intrusion review.
- Three BOM rows (25 total), README teaching and blank physical-measurement gates.

## Evidence

- Four standard-library Python frame tests pass; scoped Ruff checks pass.
- CAD checks pass for connected positive-volume solids and STEP roundtrips.
- 25 sampled combinations spanning nominal firmware offsets yaw±30/pitch±20:
  no detected positive-volume intrusion. Sampling checks actual candidate solids
  and coarse component envelopes; a positive control confirms intrusion detection.
- Point transforms agree with CAD envelope-centre transforms within 1e-6 mm.
- Firmware min/centre/max read from source and checked against sample endpoints.
- No firmware logic change, no new embedded/hardware execution claim. Python
  coordinate tests added to CI; CadQuery checks run locally, not lightweight CI.

## Still unfinished

Actual horns, shaft offsets, retention, opposite-side pitch bearing, load path,
wire routes, backlash, material strength, fasteners, optical pose and actual servo
travel remain unverified. The supplied servo body dimensions do not define its
shaft coordinate system. Sampled non-intrusion does not prove a clearance margin,
continuous sweep, pinch protection or stable camera tracking.

Next mechanical work requires real part measurements before attaching motors.
Further software work can independently improve detector/tracking input validation
and user calibration workflows without pretending these CAD assumptions are measured.

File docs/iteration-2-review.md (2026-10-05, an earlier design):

# Engineering review — iteration 2, 5 October 2026

Disposition: **continue; electrical and mechanical drafts are not hardware-approved**.

## Changes

- Replaced AHCT125 with dual-supply TXU0102 and explicit OE control/pull-down.
  Selection is based on TI's specified partial-power-down behavior, not bench evidence.
- Added two isolated NC power-cut contacts: motor power interruption and a
  low-level auxiliary contact. Opening the auxiliary input disarms; closing alone
  does not re-arm. Broken-open wiring inhibits arm.
- Added servo-side pull-downs, logic bypass capacitor and motor-rail bleeder.
- Bounded serial processing so input cannot occupy an unbounded loop iteration.
- Updated schematic, 22-row BOM, six-envelope layout, GPIO assignments and manuals.
- Added editable yaw-seat and camera-saddle CAD with slotted mounting feet and a
  common coordinate frame. Candidate parts still need positive retention, measured
  interfaces and the missing rotating/pitch carriers.

## Evidence

| Check | Result |
| --- | --- |
| Native production-controller logic | PASS, including contact-open inhibit, OE disable, no automatic re-arm |
| XIAO Sense firmware | Compile PASS; RAM 22,964 bytes, flash 350,309 bytes |
| DevKit firmware | Compile PASS; RAM 19,056 bytes, flash 313,301 bytes |
| Layout CAD | Seven-solid STEP round-trip PASS |
| Two candidate mounts | Each valid connected solid, positive volume, no assumed-envelope intrusion, STEP re-import PASS |
| Combined mounting STEP | Four bodies retained (two parts and two reference envelopes) |

No physical stop time, back-feed, startup transient, thermal result, printed fit,
load capacity, moving collision check or servo performance was measured.

## Known limitations and next steps

1. MCU polling is not a safety controller. A welded contact is not diagnosed;
   independent motor-supply loss/return is not sensed. Bench review must verify
   that the power pole actually interrupts energy, with supported loads.
2. Exact TXU breakout, switch/contact ratings and connector procurement remain open.
3. Complete a rotating yaw-to-pitch carrier using measured horn axes/fasteners;
   camera saddle is currently floating. Match mounting-foot patterns to the base.
4. Inspect lens/antenna/USB keepouts and cable travel from real measurements.
5. Run and record every condition in the power/interlock worksheet. Do not promote
   mathematical RC estimates or host tests into measured hardware claims.

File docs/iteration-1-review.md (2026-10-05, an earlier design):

# Engineering review — iteration 1, 5 October 2026

Disposition: **continue; not a finished or hardware-validated product**.

## Delivered

- XIAO Sense red-marker capture task connected to the two-axis controller.
- Explicit arming, PWM disable, finite input validation, bounded control interval,
  stale-target timeout, serial mode and status feedback.
- 14-row component BOM, nine-net module schematic, six component envelopes,
  placement drawing, editable manifest, drilled fixture STEP/STL and layout STEP.
- README quick start, detailed build/manual and four hands-on lessons.

## Evidence actually obtained

- PlatformIO 6.2.0 / Espressif32 6.10.0: XIAO Sense and DevKitC builds PASS.
- Native C++ production-controller tests with mocked GPIO/time: PASS for boot
  disarmed, enable/disable, travel limits, deadband, finite input rejection,
  750 ms expiry, 40 ms catch-up cap, timer rollover and RGB565 marker detection.
- CadQuery 2.8.0: valid positive-volume fixture; layout STEP round-trip seven solids.
- Manifest validates unique references, sourced selections, geometry and connected nets.
- CI workflow added; remote workflow outcome must be checked after push.

No motor, camera, power-cut, current, temperature or printed part was tested.

## Next iteration, in priority order

1. Resolve independent signal isolation on power-cut; validate power-off states
   against component datasheets before presenting wiring as a build release.
2. Design parameterized yaw/pitch brackets with explicit measured-interface gates;
   separate placeholders from fabrication-ready geometry. Record horn-axis offsets.
3. Add electrical load budget, harness/connector schedule and recorded bench worksheets.
4. Exercise serial parser and camera failures; add image fixtures and polarity checks.
5. Physical owner: measure horns/holes, scope signals, verify limits/power-cut, run
   restrained marker trials and endurance test. This step cannot be simulated away.

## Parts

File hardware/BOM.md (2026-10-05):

# Tracker Bot EVT-A.1 — bill of materials

Bench red-marker tracker; XIAO Sense + two PWM servos. MCU USB and motor 4.8 V rails are separate. No production approval.

Prices and procurement approval are not supplied. Quantities are per prototype.

| Ref | Qty | Selection / value | Selection status | Source |
| --- | ---: | --- | --- | --- |
| U1 | 1 | XIAO ESP32-S3 Sense | Selected camera/controller; dimensions are clearance envelope | [Seeed pin map](https://wiki.seeedstudio.com/xiao_esp32s3_getting_started/) |
| J1 | 1 | USB host / power cable | Prototype selection; bench verification required | [Design rationale](../docs/engineering.md) |
| P1 | 1 | Regulated 4.8 V motor supply | Set current limit 0.5 A initially; qualify up to 3 A | [Design rationale](../docs/engineering.md) |
| F1 | 1 | 2 A fuse + holder | Initial fuse value; coordinate with measured inrush | [Design rationale](../docs/engineering.md) |
| S1 | 1 | Latching power-cut switch, two isolated NC contacts | Power pole >=5 A DC at 5 V; aux pole rated for low-level signal; exact part TBD | [Design rationale](../docs/engineering.md) |
| U2 | 1 | TXU0102DCUR on verified VSSOP8 breakout | Dual-supply A-to-B translator; IC pin numbers, not breakout terminal numbers | [TI TXU0102 datasheet](https://www.ti.com/lit/ds/symlink/txu0102.pdf) |
| R1 | 1 | 10k input pull-down | Prototype selection; bench verification required | [Design rationale](../docs/engineering.md) |
| R2 | 1 | 10k input pull-down | Prototype selection; bench verification required | [Design rationale](../docs/engineering.md) |
| C1 | 1 | 100 nF ceramic / >=10 V | Prototype selection; bench verification required | [Design rationale](../docs/engineering.md) |
| C2 | 1 | 470 uF electrolytic / >=10 V | Observe polarity; near servo connectors | [Design rationale](../docs/engineering.md) |
| M1 | 1 | TowerPro SG90 yaw | Case envelope; shaft axis +Z, horn attachment TBD | [TowerPro SG90](https://towerpro.com.tw/product/sg90-analog/) |
| M2 | 1 | TowerPro SG90 pitch | Rotated case envelope; shaft axis +Y, bracket TBD | [TowerPro SG90](https://towerpro.com.tw/product/sg90-analog/) |
| R3 | 1 | 10k OE pull-down | Keeps translator disabled during MCU reset | [Electrical review](../docs/power-and-interlock.md) |
| R4 | 1 | 47k yaw PWM pull-down | Servo-side signal bias when translator output is high impedance | [Electrical review](../docs/power-and-interlock.md) |
| R5 | 1 | 47k pitch PWM pull-down | Servo-side signal bias when translator output is high impedance | [Electrical review](../docs/power-and-interlock.md) |
| R6 | 1 | 10k stop-contact pull-up | Open aux contact or broken wire -> logic high -> disarm | [Electrical review](../docs/power-and-interlock.md) |
| R7 | 1 | 1k 0.25W motor-rail bleeder | Nominal 23mW at 4.8V; discharge timing must be measured | [Electrical review](../docs/power-and-interlock.md) |
| C3 | 1 | 100nF ceramic / >=10V logic bypass | At TXU0102 pins 3 and 2 | [TI TXU0102 datasheet](https://www.ti.com/lit/ds/symlink/txu0102.pdf) |
| H3 | 1 | Draft yaw servo seat (parametric printed candidate) | NOT fabrication approved; retention/fit unresolved; candidate plate holes now supplied | [Mechanical draft guide](../mechanical/README.md) |
| H4 | 1 | Draft camera saddle (parametric printed candidate) | NOT fabrication approved; rests on candidate pitch carrier; actual horn connection unresolved | [Mechanical draft guide](../mechanical/README.md) |
| H5 | 1 | Candidate yaw-to-pitch carrier | Parametric draft; supplied-horn attachment and servo retention NOT defined | [Carrier and frame review](../mechanical/carrier-review.md) |
| H6 | 1 | Candidate pitch-to-camera carrier | Parametric draft; pitch horn pattern and shaft load review unresolved | [Carrier and frame review](../mechanical/carrier-review.md) |
| H7 | 4 | M3 candidate mount fastener sets | Two yaw-seat/plate plus two saddle/carrier joints; length, access and locking TBD | [Carrier and frame review](../mechanical/carrier-review.md) |
| H1 | 4 | M3 fixture screw + nut + washer set | For plate holes; not servo screws | [Design rationale](../docs/engineering.md) |
| H2 | 2 | Servo manufacturer horn and screw | Reuse supplied horn; do not guess spline or screw length | [Design rationale](../docs/engineering.md) |

## Net connections

Identical labels in the schematic are electrically connected.
NC means intentionally unconnected. Supply and connector ratings need physical verification.

- **USB_HOST**: U1.USB, J1.USB
- **GND**: U1.GND, J1.GND, P1.NEG, S1.AUX NC, U2.2 GND, R1.2, R2.2, C1.2, C2.NEG, M1.GND, M2.GND, R3.2, R4.2, R5.2, R7.2, C3.2
- **YAW_IN**: U1.D0 / GPIO1, U2.5 A1, R1.1
- **PITCH_IN**: U1.D1 / GPIO2, U2.4 A2, R2.1
- **LOGIC_3V3**: U1.3V3, U2.3 VCCA, R6.1, C3.1
- **PWM_ENABLE**: U1.D2 / GPIO3, U2.6 OE, R3.1
- **STOP_SENSE**: U1.D3 / GPIO4, S1.AUX COM, R6.2
- **MOTOR_RAW**: P1.POS, F1.IN
- **MOTOR_FUSED**: F1.OUT, S1.POWER COM
- **MOTOR_4V8**: S1.POWER NC, U2.7 VCCB, C1.1, C2.POS, M1.V+, M2.V+, R7.1
- **YAW_PWM**: U2.8 B1Y, M1.PWM, R4.1
- **PITCH_PWM**: U2.1 B2Y, M2.PWM, R5.1

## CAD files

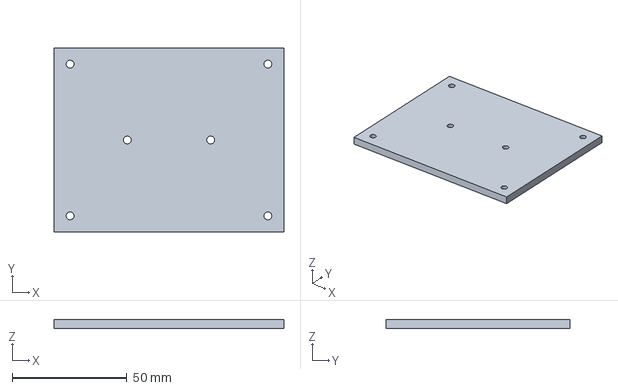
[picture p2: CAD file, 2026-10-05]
mechanical/carrier-fixture-plate.step
100.0 x 80.0 x 4.00 mm

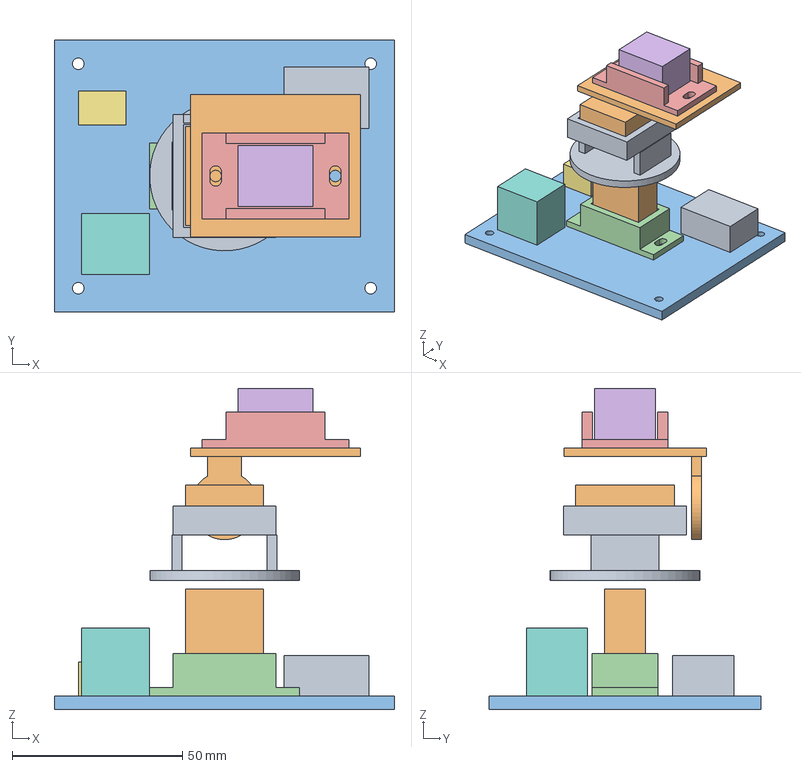
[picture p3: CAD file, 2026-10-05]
mechanical/carrier-layout.step
100.0 x 80.0 x 94.5 mm
yaw-carrier-draft
pitch-carrier-draft
carrier-fixture-plate
yaw_seat
camera_saddle
U1
F1
S1
U2
M1
M2

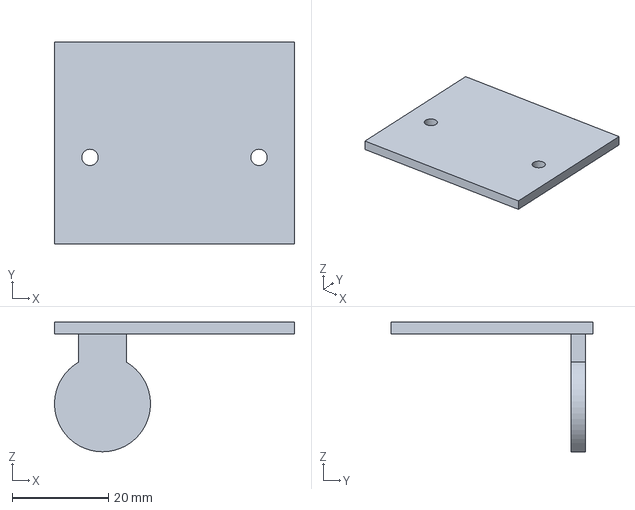
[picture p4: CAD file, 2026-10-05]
mechanical/pitch-carrier-draft.step
50.0 x 42.0 x 27.0 mm

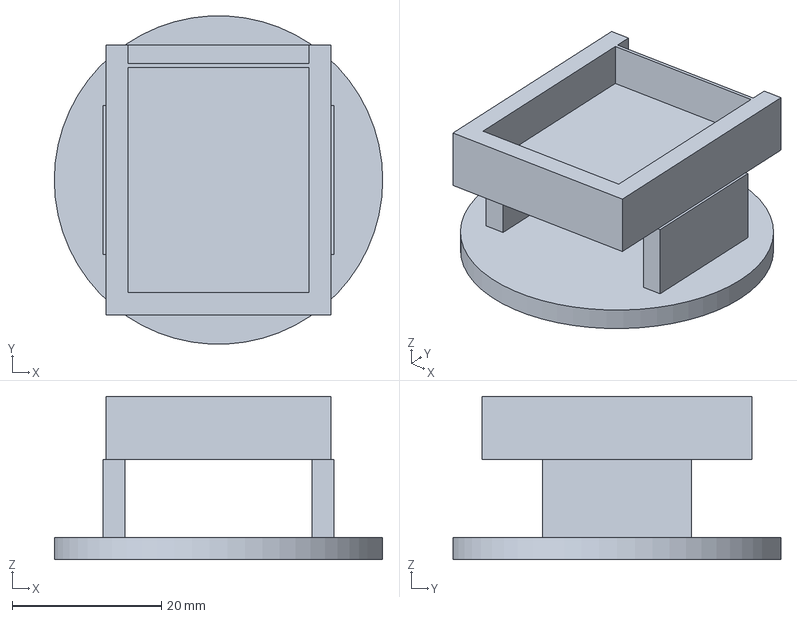
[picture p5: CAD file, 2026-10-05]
mechanical/yaw-carrier-draft.step
44.0 x 43.9 x 21.9 mm

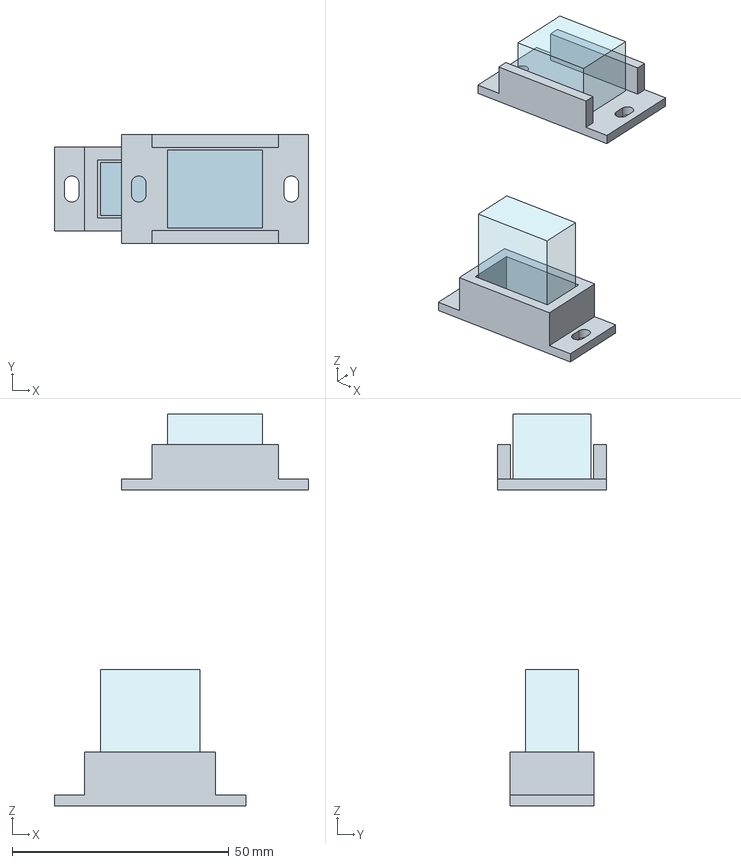
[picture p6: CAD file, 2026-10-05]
mechanical/mounting-drafts.step
58.7 x 25.2 x 90.5 mm
yaw-seat-draft
M1_ASSUMED_ENVELOPE
camera-saddle-draft
U1_ASSUMED_ENVELOPE

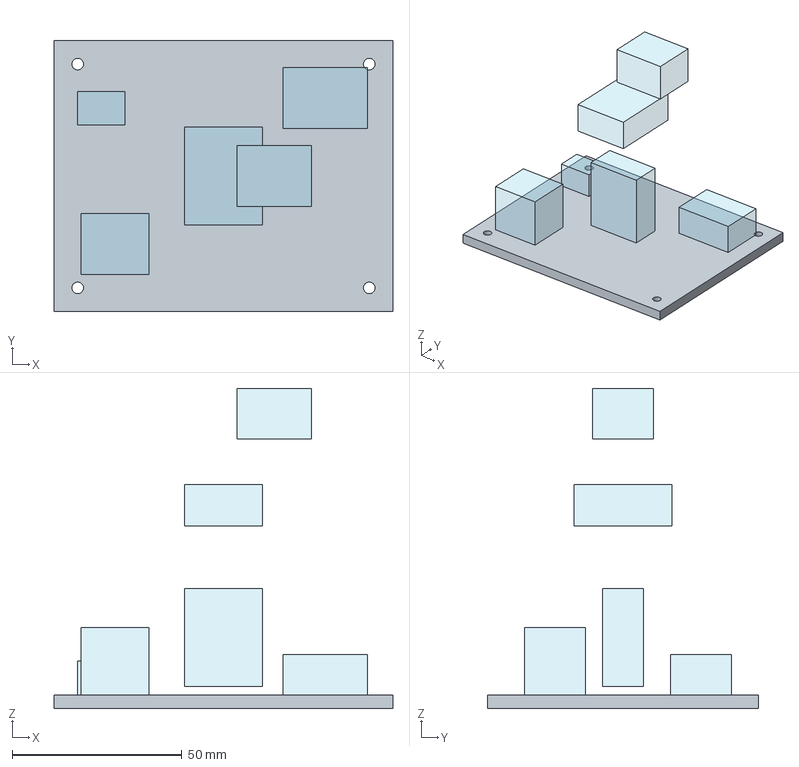
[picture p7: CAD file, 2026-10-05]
mechanical/layout-draft.step
100.0 x 80.0 x 94.5 mm
fixture_plate
U1_ENVELOPE
F1_ENVELOPE
S1_ENVELOPE
U2_ENVELOPE
M1_ENVELOPE
M2_ENVELOPE

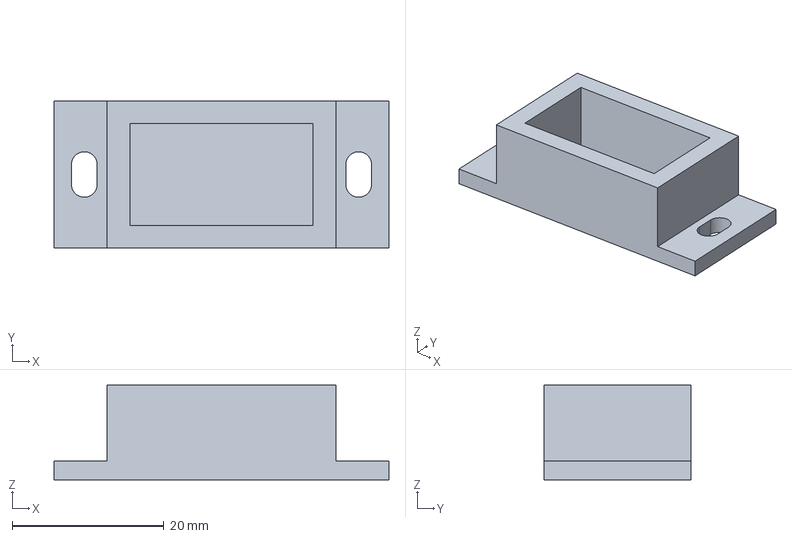
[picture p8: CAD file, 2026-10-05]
mechanical/yaw-seat-draft.step
44.2 x 19.4 x 12.5 mm

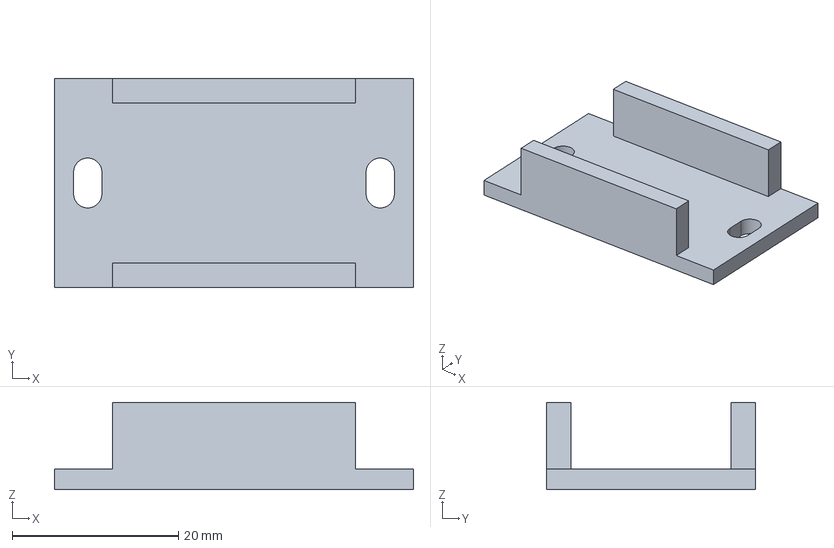
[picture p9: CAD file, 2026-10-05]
mechanical/camera-saddle-draft.step
43.2 x 25.2 x 10.5 mm

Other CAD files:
mechanical/fixture-plate.step
mechanical/camera-saddle-draft.stl
mechanical/carrier-fixture-plate.stl
mechanical/fixture-plate.stl
mechanical/pitch-carrier-draft.stl
mechanical/yaw-carrier-draft.stl
mechanical/yaw-seat-draft.stl

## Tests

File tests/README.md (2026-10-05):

# Software checks (no hardware attached)

Compile the production controller and servo sources against the tiny GPIO/timer
shim in `native/`; this tests logic, not actual PWM signals or motor behavior.
With a C++17 compiler, from the repository root:

```sh
c++ -std=c++17 -Itests/native -Ifirmware/include tests/native/test_control.cpp firmware/src/tracker_controller.cpp firmware/src/servo_axis.cpp -o /tmp/tracker-tests
/tmp/tracker-tests
```

On Windows, `python -m pip install ziglang==0.13.0` provides an optional compiler.
Replace `c++` with `python -m ziglang c++` and choose an output path under an ignored
`build/` directory. Embedded compilation is separate: `pio run -d firmware`.
Neither test substitutes for the staged electrical and mechanical acceptance
procedure in `docs/engineering.md`.

The same native binary tests the production `camera_frame.h` boundary: exact
RGB565 dimensions/length, capture-age boundaries, malformed/future timestamps,
overflow-resistant conversion, millisecond rollover, red sample threshold,
green/white rejection and original capture timestamp preservation into control.
Camera metadata and GPIO/time are synthetic; FreeRTOS scheduling, actual DMA
buffers, byte order, sensor output and PWM are not exercised on hardware.

The connected-region detector has a separate strict-warning native test:

```sh
c++ -std=c++17 -Wall -Wextra -Werror -Ifirmware/include tests/native/test_red_components.cpp -o /tmp/red-tests
/tmp/red-tests
```

It checks unique and ambiguous candidates, subthreshold split regions, speckles
not shifting the centroid, diagonal versus side-connected contact, full-frame
4,800-sample capacity with workspace canaries, checkerboard noise, edge/odd-size
inputs and reuse without stale samples. Full-red and bridged-region acceptance
are explicitly tested **limitations**, not proof of object recognition. The
14,400-byte workspace belongs to the capture task; concurrent callers require
separate workspaces. No native timing result is an ESP32 latency measurement.

Run the production serial parser, fixed line buffer and command effects against
the real controller/servo sources and host shim:

```sh
c++ -std=c++17 -Wall -Wextra -Werror -Itests/native -Ifirmware/include tests/native/test_serial.cpp firmware/src/tracker_controller.cpp firmware/src/servo_axis.cpp -o /tmp/serial-tests
/tmp/serial-tests
```

Cases include strict argument counts/numeric grammar, invalid-input cancellation,
wrong input mode, interlock precedence, PWM hold versus disable, 96/97-byte
boundaries, NUL/non-ASCII rejection, CRLF, timeout/recovery and clock rollover.
The full UART/USB driver and main-loop scheduling are not simulated by this test.

The camera-stream test includes production `main.cpp` and the real controller /
servo code, with scripted serial input, queued camera results, GPIO and time:

```sh
c++ -std=c++17 -Wall -Wextra -Werror -Itests/native -Ifirmware/include tests/native/test_camera_stream.cpp firmware/src/tracker_controller.cpp firmware/src/servo_axis.cpp -o /tmp/camera-stream-tests
/tmp/camera-stream-tests
```

It checks startup without images, exact 750/751 ms capture-age boundaries,
future/old receipt timestamps, task silence, invalid/no-frame/stale results,
explicit reselection after stream recovery, normal marker-loss/ambiguity recovery,
one-time fault reporting, held PWM, serial-mode independence, stop contact,
disarmed selection and timer rollover. This tests loop ordering, not real FreeRTOS
scheduling, blocked drivers, a frozen MCU, camera restart or electrical stopping.

The PWM initialization test also includes production `main.cpp` and uses a shim
that models the S3's 14-bit limit and records setup/write/attach/OE event order:

```sh
c++ -std=c++17 -Wall -Wextra -Werror -Itests/native -Ifirmware/include tests/native/test_pwm_init.cpp firmware/src/tracker_controller.cpp firmware/src/servo_axis.cpp -o /tmp/pwm-init-tests
/tmp/pwm-init-tests
```

It injects zero/49/51 Hz results for each axis, checks both-axis arming inhibition,
startup/status messages, no automatic retry, zero duty before attaching a pin,
both pulse commands before OE high, OE low before disabling pulses, direct-axis
pre-setup rejection and deliberate reinitialization. An independent arithmetic
sweep checks pulse quantization within half a 14-bit period count. This is not a
measurement of pin routing, waveform quality, clock accuracy or power transients.

Coordinate math tests (standard-library Python, also in CI):
`python -m unittest discover -s tests -p test_frames.py`. These check right-handed
axes, pivot/distance preservation, pitch-before-yaw composition and invalid inputs.
The optional CadQuery generator `python tools/build_carriers.py` performs local
25-pose solid/envelope intrusion checks; it is not part of lightweight CI and
does not establish continuous clearance or physical calibration.

`python -m unittest discover -s tests -p test_visual_review.py` checks freshness
of the committed visual review using source/image hashes and a PNG size check.
It runs in CI without CadQuery. To regenerate after geometry changes, use
`python tools/render_carrier_review.py` with CadQuery 2.8.0 and Matplotlib 3.11.2,
then visually inspect the result. Hash agreement is not geometric/physical approval.

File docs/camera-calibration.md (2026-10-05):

# Camera input and calibration lesson

Revision: 5 October 2026. **Unexecuted physical worksheet.** Native software tests
and embedded builds are not evidence that a real camera or mechanism works.

## Frame contract and corrected age

The reference mode is tightly packed, MSB-first RGB565 at 160x120 (38,400 bytes).
The capture boundary rejects other metadata before reading pixels. Red is a
simple channel-dominance threshold, sampled on every second row/column, with a
minimum of 20 red samples **per four-connected region** on the sampled grid.
Exactly one qualifying region is required. With two or more, the result is
`ambiguous`, coordinates are cleared and delivered results stop increments.
Smaller disconnected regions are excluded from the accepted region's centroid.
A one-pixel shift can change sampled counts and connectivity.

This is not object identity recognition. Touching regions or a sampled red bridge
merge into one region; a red wall can qualify. A lone distractor can become the
accepted region when the original marker leaves, and re-entry remains automatic.
No area upper bound, shape model, temporal association or identity lock is provided.
The 20-sample threshold is an uncalibrated experiment setting, not a confidence score.

The old path assigned the time of frame retrieval, allowing a buffered old
image to appear recent. The corrected path preserves capture-start time, rejects
invalid or future times and ages frames against the boot-relative timer before
processing. It retains that timestamp through the queue and controller; a target
is eligible through age 750 ms and expires beyond it. This is a chosen software
limit, not a measured safety stop time. At consumption, ordinary control-loop
scheduling adds latency; a frozen MCU is not covered by these checks.

Evidence: the installed Arduino-ESP32 2.0.17 camera header describes the timestamp
as boot-relative first-DMA-buffer time. Upstream
[camera acquisition source](https://github.com/espressif/esp32-camera/blob/v2.0.4/driver/cam_hal.c)
assigns it using `esp_timer_get_time`; Arduino 2.0.17
[`millis()` implementation](https://github.com/espressif/arduino-esp32/blob/2.0.17/cores/esp32/esp32-hal-misc.c)
uses that timer divided by 1000. The installed header SHA-256 is
`fb13779551477d5e9baf2af721e3a9d5e4625ba66114b687d25ed15e3edffd23`.
This source/header review is not a measurement of the bundled camera driver's
timing on either sensor revision; verify with the actual board.

## Operator behaviour

| Observation | Control response while armed in camera mode |
| --- | --- |
| Fresh valid marker | Bounded incremental targets; no encoder feedback |
| Fresh no-marker/ambiguous image | Stop new increments; keep last PWM and camera mode |
| Delivered invalid/stale/no-frame result | Stop increments, exit camera mode; keep last PWM |
| Capture age exceeds 750 ms, including silent/stalled capture | Stop increments, exit camera mode; keep last PWM |
| Fresh marker after ordinary marker loss | Automatically resumes only while camera mode remains selected |
| Fresh image after stream fault | Stream becomes live, but tracking stays off until explicit `camera` selection |
| `stop` or `serial` | Exit camera mode and stop tracking increments |
| `disarm` or open auxiliary stop contact | Disable PWM/OE; payload may fall; physical power cut still required |

`status` prints `last_frame`, `red_samples` (all red samples), `candidates`
(regions with at least 20 samples), `selected_samples` (accepted region only,
zero when none/ambiguous), and (where a timestamp is valid)
`capture_age_ms`. `camera_stream` reports `waiting`, `live`, `no-frame`,
`invalid-frame`, `stale-frame` or `timed-out` (`unavailable` if capture setup failed).
An old `marker` label can persist after a task hangs: it means last received
result, not a continuously healthy camera. Check stream, age, input and target.
Camera processing remains active in serial/disarmed modes; no network upload is
implemented. `stop` is not a camera privacy shutter or motor-power isolation.

### Stream-fault recovery exercise (no motors connected)

Run the actual-main-loop native test in [tests/README.md](../tests/README.md).
It scripts camera queues/time without touching a physical board:

1. Camera initialization alone must not permit camera mode: no fresh image yet.
2. A marker captured at 520 ms remains eligible through 1270 ms, not 1271 ms.
   Receipt of an old image never extends its capture lifetime. At expiry the
   application exits camera mode but keeps its armed/held-PWM state.
3. A fresh marker after the fault updates stream health but does not resume
   tracking. An explicit `camera` command selects the recovered stream; motion
   requires a newly delivered valid marker and separately armed motors.
4. Contrast fresh no-marker/ambiguous images: these keep the stream live and
   allow ordinary reacquisition. Test a stop-contact opening and clock rollover.

This is a **main-loop freshness gate**, not an independent watchdog or fault-
tolerant controller. Frozen MCU/main loop, blocked serial output, real queue
scheduling and PWM electronics remain untested. There is no camera-task restart,
motor-power removal or encoder confirmation. Serial target mode stays independent
of camera health. Do not hot-unplug a camera flex cable to induce a fault; physical
fault injection requires a reviewed, de-energized setup and separate test plan.

## Connected-region exercise (motors disconnected)

Run the native component test in [tests/README.md](../tests/README.md). It uses
synthetic RGB565: one region qualifies; two separated 20-sample regions reject;
24 samples split into two 12-sample regions do not qualify; isolated speckles
do not pull the accepted centroid. Diagonal-only contact stays separate, while
a one-sample side-connected bridge merges regions. Explain why the last result
is a limitation rather than evidence of reliable object identity.

On the actual camera, record the same trials with motors disconnected and a
plain background. Log candidate/selected counts, lighting and capture age. Do
not widen travel or enable motion based solely on synthetic passing cases.
Capture owns a fixed 14,400-byte workspace outside its 4,096-byte task stack;
the flood fill visits each sampled cell at most once, without recursion or heap
allocation. QQVGA is the maximum supported detector size. Actual processing
latency, stack high-water mark and available runtime heap still need measurement.

## Teaching procedure

1. With motors disconnected, run native tests. Change a synthetic frame timestamp
   from 750,000 to 750,001 microseconds old and explain the boundary. Contrast
   capture, retrieval, processing and command time.
2. Identify the actual camera/sensor/PCB revision. Keep the mechanism restrained;
   leave motors disconnected for the image tests. Use one red card on a plain
   background. Record left/right/top/bottom placement, red sample counts and
   lighting. Byte order and orientation must be established, not assumed.
3. Under the separate approved low-energy bench procedure, verify each actuator
   direction independently. Initial arming applies stored position and can move
   abruptly. Default `target` input is a velocity-like error, NOT a one-degree
   command; do not infer physical angle from the serial input. Use externally
   measured displacement and the physical power cut as needed.
4. Record whether a small positive actuator change reduces or increases each
   image error. The current positive-gain control requires its own-axis error to
   decrease for a positive actuator change. Correct polarity only after measured
   evidence; record cross-axis response too. The worksheet is not camera intrinsic
   calibration, an optical-frame transform, or a closed-loop stability proof.
5. Test loss and re-entry with the supported no-payload mechanism. Record PWM,
   commanded angle and actual motion separately. Demonstrate that `stop` prevents
   camera-driven resumption and that contact release alone does not arm.
6. Keep failed trials and environmental conditions. Do not tune gains or widen
   travel to hide poor detection, incorrect polarity or mechanical interference.

## Physical worksheet — all results pending

| Record | Actual result / evidence file |
| --- | --- |
| Operator, observer, date, firmware commit/build environment | pending |
| Board/sensor marking, lens, PCB revision and photos | pending |
| Independent restraint, power cut, current limit and horns/payload configuration | pending |
| Captured format/dimensions, byte-order evidence, sensor mirror/flip | pending |
| Marker physical size, distance, lighting/background for each trial | pending |
| Four image quadrants: observed direction and red sample counts | pending |
| Measured yaw change versus horizontal/vertical image-error change | pending |
| Measured pitch change versus horizontal/vertical image-error change | pending |
| Capture-age distribution and independent timing method | pending |
| Marker loss: last capture, last incremental PWM command, physical stopping | pending |
| Re-entry behaviour, two-red-object and non-red distractor trials | pending |
| Stop/serial/disarm behaviour and separate power-cut response | pending |
| Accepted polarity, gain, bounds, unresolved issues and reviewer signoff | pending |

Do not copy simulation outputs into measured fields. Production needs actual
identity/target selection, obstruction/current sensing, validated mechanics and
independent fault supervision; this educational marker prototype is not finished.

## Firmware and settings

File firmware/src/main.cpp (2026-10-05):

#include <Arduino.h>
#include <math.h>
#include "camera_target.h"
#include "camera_frame.h"
#include "camera_stream.h"

#include "app_config.h"
#include "servo_axis.h"
#include "tracker_controller.h"
#include "serial_command.h"

ServoAxis yawAxis(config::kYawServoPin, config::kYawPwmChannel,
                  config::kYawMinDeg, config::kYawCenterDeg,
                  config::kYawMaxDeg);
ServoAxis pitchAxis(config::kPitchServoPin, config::kPitchPwmChannel,
                    config::kPitchMinDeg, config::kPitchCenterDeg,
                    config::kPitchMaxDeg);
TrackerController tracker(yawAxis, pitchAxis);

SerialLineBuffer serialInput;
bool cameraReady = false;
bool cameraMode = false;
CameraStreamMonitor cameraStream(config::kTargetTimeoutMs);
CameraTarget lastCameraTarget{false, 0, 0, 0, 0, CameraFrameState::NoFrame, 0, 0};

void printHelp() {
  Serial.println();
  Serial.println("Tracker Bot firmware prototype");
  Serial.println("Commands:");
  Serial.println("  arm / disarm    explicit PWM enable / disable (support payload)");
  Serial.println("  camera / serial choose marker camera or serial target input");
  Serial.println("  target <x> <y>  x/y from -1.0 to +1.0");
  Serial.println("  center          center both axes");
  Serial.println("  stop            stop tracking motion");
  Serial.println("  status          print current state");
  Serial.println("  help            show this message");
  Serial.println("Example: target 0.35 -0.20");
  Serial.println("ASCII lines: max 96 bytes; finish within 1 s; invalid input stops tracking, not PWM");
}

void printStatus() {
  Serial.printf("armed=%s, input=%s, camera=%s, yaw=%.1f deg, pitch=%.1f deg, target=%s\n",
                tracker.isArmed() ? "yes" : "no", cameraMode ? "camera" : "serial",
                cameraReady ? "ready" : "unavailable", yawAxis.angle(),
                pitchAxis.angle(), tracker.hasTarget(millis()) ? "yes" : "no");
  Serial.printf("stop_contact=%s\n", tracker.interlockClosed() ? "closed" : "OPEN: arm inhibited");
  Serial.printf("pwm_setup=%s (driver result only; waveform unverified)\n",
                tracker.pwmReady() ? "ready" : "FAILED: arm inhibited");
  Serial.printf("camera_stream=%s\n", cameraReady ? cameraStream.state(millis()) : "unavailable");
  Serial.printf("last_frame=%s, red_samples=%lu, candidates=%u, selected_samples=%lu",
                cameraFrameStateName(lastCameraTarget.state),
                static_cast<unsigned long>(lastCameraTarget.pixels),
                static_cast<unsigned>(lastCameraTarget.candidates),
                static_cast<unsigned long>(lastCameraTarget.selectedPixels));
  if (lastCameraTarget.state == CameraFrameState::Marker ||
      lastCameraTarget.state == CameraFrameState::NoMarker ||
      lastCameraTarget.state == CameraFrameState::Ambiguous ||
      lastCameraTarget.state == CameraFrameState::StaleFrame)
    Serial.printf(", capture_age_ms=%lu", static_cast<unsigned long>(millis() - lastCameraTarget.timestamp));
  Serial.println();
}

void handleCommand(const char* line) {
  const auto command = parseSerialCommand(line);
  const char* message = applySerialCommand(command, tracker, cameraMode,
      cameraReady && cameraStream.usable(millis()),
      digitalRead(config::kStopSensePin) == LOW, millis());
  if (message) Serial.println(message);
  if (command.kind == CommandKind::Status) printStatus();
  if (command.kind == CommandKind::Help) printHelp();
}

void rejectSerialLine() {
  cameraMode = false; tracker.stopTracking();
  Serial.println("Invalid or expired line: tracking stopped; send newline then a new command");
}

void readSerialCommands() {
  // Bound serial work so a continuous input stream cannot starve the stop check.
  if (serialInput.expire(millis())) rejectSerialLine();
  uint16_t consumed = 0;
  while (Serial.available() > 0 && consumed++ < 128) {
    const auto event = serialInput.push(static_cast<uint8_t>(Serial.read()), millis());
    if (event == LineEvent::Complete) handleCommand(serialInput.line());
    if (event == LineEvent::Rejected) rejectSerialLine();
  }
}

void setup() {
  tracker.begin();
  pinMode(config::kStopSensePin, INPUT_PULLUP);
  Serial.begin(115200);
  delay(500);
  if (!tracker.pwmReady()) Serial.println("PWM initialization FAILED: arming blocked; inspect configuration and restart");
  cameraReady = startCameraTarget();
  Serial.println(cameraReady ? "Camera ready; motors DISARMED" : "Serial-only; motors DISARMED");
  printHelp();
}

void loop() {
  const bool stopClosed = digitalRead(config::kStopSensePin) == LOW;
  tracker.setInterlockClosed(stopClosed);
  if (!stopClosed) cameraMode = false;
  CameraTarget target{};
  const bool received = readCameraTarget(target);
  if (received) {
    lastCameraTarget = target;
    cameraStream.observe(target, millis());
  }
  // Poll health before commands: camera selection needs a currently fresh image,
  // not merely successful initialization at boot.
  if (cameraMode && !cameraStream.usable(millis())) {
    cameraMode = false;
    tracker.stopTracking();
    Serial.println("Camera stream fault: tracking stopped; PWM held. Fresh frames + camera required");
  }
  readSerialCommands();
  if (received && cameraMode) {
    if (target.found && millis() - target.timestamp <= config::kTargetTimeoutMs)
      tracker.updateTarget(target.x, target.y, target.timestamp);
    else tracker.stopTracking();
  }
  tracker.tick(millis());

  delay(1);
}

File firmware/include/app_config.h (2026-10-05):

#pragma once

#include <Arduino.h>
#ifdef ARDUINO_ARCH_ESP32
#include "soc/soc_caps.h"
#endif

namespace config {

// Change these pins before connecting hardware. Avoid pins used by the camera,
// flash, PSRAM, or USB on your final ESP32-S3 board.
#ifdef TRACKER_XIAO_SENSE
constexpr uint8_t kYawServoPin = 1;    // D0; camera pins are separate.
constexpr uint8_t kPitchServoPin = 2;  // D1.
constexpr uint8_t kPwmEnablePin = 3;   // D2 -> TXU0102 OE.
constexpr uint8_t kStopSensePin = 4;   // D3 -> separate NC stop contact to GND.
#else
constexpr uint8_t kYawServoPin = 4;
constexpr uint8_t kPitchServoPin = 5;
constexpr uint8_t kPwmEnablePin = 6;
constexpr uint8_t kStopSensePin = 7;
#endif

constexpr uint8_t kYawPwmChannel = 0;
constexpr uint8_t kPitchPwmChannel = 1;
constexpr uint16_t kServoPwmFrequencyHz = 50;
// ESP32-S3 LEDC timers support at most 14 bits, not classic ESP32's 20.
constexpr uint8_t kServoPwmResolutionBits = 14;
#ifdef ARDUINO_ARCH_ESP32
static_assert(kServoPwmResolutionBits <= SOC_LEDC_TIMER_BIT_WIDE_NUM,
              "Servo PWM resolution exceeds this chip's LEDC capability");
static_assert(kYawPwmChannel < SOC_LEDC_CHANNEL_NUM && kPitchPwmChannel < SOC_LEDC_CHANNEL_NUM,
              "Servo PWM channel is unavailable on this chip");
#endif

// Start with conservative limits and widen them only after checking the CAD.
constexpr float kYawMinDeg = 60.0F;
constexpr float kYawCenterDeg = 90.0F;
constexpr float kYawMaxDeg = 120.0F;
constexpr float kPitchMinDeg = 70.0F;
constexpr float kPitchCenterDeg = 90.0F;
constexpr float kPitchMaxDeg = 110.0F;

// Typical hobby-servo pulse range. Confirm it against the selected servo.
constexpr uint16_t kServoMinPulseUs = 1000;
constexpr uint16_t kServoMaxPulseUs = 2000;

// Target coordinates are normalized: -1 is left/up and +1 is right/down.
constexpr float kTargetDeadband = 0.08F;
constexpr float kYawGainDegPerSecond = 55.0F;
constexpr float kPitchGainDegPerSecond = 45.0F;
constexpr uint32_t kTargetTimeoutMs = 750;
constexpr uint32_t kControlPeriodMs = 20;

}  // namespace config

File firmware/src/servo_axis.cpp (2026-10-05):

#include "servo_axis.h"

#include "app_config.h"
#include <math.h>

namespace {

uint32_t pulseToDuty(float pulseUs) {
  constexpr uint32_t kPeriodUs =
      1000000UL / config::kServoPwmFrequencyHz;
  constexpr uint32_t kCountsPerPeriod = 1UL << config::kServoPwmResolutionBits;
  return static_cast<uint32_t>(lroundf(pulseUs * kCountsPerPeriod / kPeriodUs));
}

}  // namespace

ServoAxis::ServoAxis(uint8_t pin, uint8_t channel, float minimumDeg,
                     float centerDeg, float maximumDeg)
    : pin_(pin),
      channel_(channel),
      minimumDeg_(minimumDeg),
      centerDeg_(centerDeg),
      maximumDeg_(maximumDeg),
      angleDeg_(centerDeg) {}

void ServoAxis::begin() {
  disable();
  ready_ = false;
  const uint32_t actualHz = ledcSetup(channel_, config::kServoPwmFrequencyHz,
                                    config::kServoPwmResolutionBits);
  if (actualHz != config::kServoPwmFrequencyHz) return;
  ready_ = true;
  // Attach inherits channel duty in pinned Arduino 2.0.17; zero it first.
  ledcWrite(channel_, 0);
  ledcAttachPin(pin_, channel_);
}

void ServoAxis::enable() {
  if (!ready_) return;
  enabled_ = true; setAngle(angleDeg_);
}
void ServoAxis::disable() {
  enabled_ = false;
  if (ready_) ledcWrite(channel_, 0);
}

void ServoAxis::setAngle(float angleDeg) {
  if (!enabled_ || !isfinite(angleDeg)) return;
  angleDeg_ = constrain(angleDeg, minimumDeg_, maximumDeg_);
  const float fraction = angleDeg_ / 180.0F;
  const float pulseUs =
      config::kServoMinPulseUs +
      fraction * (config::kServoMaxPulseUs - config::kServoMinPulseUs);
  ledcWrite(channel_, pulseToDuty(pulseUs));
}

void ServoAxis::moveBy(float deltaDeg) { setAngle(angleDeg_ + deltaDeg); }

void ServoAxis::center() { setAngle(centerDeg_); }

float ServoAxis::angle() const { return angleDeg_; }

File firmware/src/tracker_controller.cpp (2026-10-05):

#include "tracker_controller.h"

#include <math.h>

#include "app_config.h"

namespace {

float applyDeadband(float value) {
  return fabsf(value) < config::kTargetDeadband ? 0.0F : value;
}

}  // namespace

TrackerController::TrackerController(ServoAxis& yaw, ServoAxis& pitch)
    : yaw_(yaw), pitch_(pitch) {}

void TrackerController::begin() {
  digitalWrite(config::kPwmEnablePin, LOW);
  pinMode(config::kPwmEnablePin, OUTPUT);
  stopTracking();
  armed_ = false;
  interlockClosed_ = false;
  yaw_.begin();
  pitch_.begin();
  lastControlMs_ = millis();
}

void TrackerController::updateTarget(float horizontalError,
                                     float verticalError,
                                     uint32_t timestampMs) {
  if (!armed_ || !isfinite(horizontalError) || !isfinite(verticalError) ||
      fabsf(horizontalError) > 1.0F || fabsf(verticalError) > 1.0F ||
      uint32_t(millis() - timestampMs) > config::kTargetTimeoutMs) {
    stopTracking();
    return;
  }
  horizontalError_ = constrain(horizontalError, -1.0F, 1.0F);
  verticalError_ = constrain(verticalError, -1.0F, 1.0F);
  lastTargetMs_ = timestampMs;
  tracking_ = true;
}

void TrackerController::arm() {
  if (!interlockClosed_ || !pwmReady()) return;
  stopTracking();
  lastControlMs_ = millis();
  yaw_.enable();
  pitch_.enable();
  digitalWrite(config::kPwmEnablePin, HIGH);
  armed_ = true;
}

void TrackerController::disarm() {
  digitalWrite(config::kPwmEnablePin, LOW);
  stopTracking();
  armed_ = false;
  yaw_.disable();
  pitch_.disable();
}

void TrackerController::setInterlockClosed(bool closed) {
  interlockClosed_ = closed;
  if (!closed) disarm();
}

void TrackerController::stopTracking() {
  tracking_ = false;
  horizontalError_ = 0.0F;
  verticalError_ = 0.0F;
}

void TrackerController::center() {
  if (!armed_) return;
  stopTracking();
  yaw_.center();
  pitch_.center();
}

bool TrackerController::hasTarget(uint32_t nowMs) const {
  return armed_ && tracking_ && (nowMs - lastTargetMs_ <= config::kTargetTimeoutMs);
}

void TrackerController::tick(uint32_t nowMs) {
  if (nowMs - lastControlMs_ < config::kControlPeriodMs) {
    return;
  }

  // Never turn a stalled event loop into a large catch-up movement.
  const float elapsedSeconds = min(nowMs - lastControlMs_, uint32_t(40)) / 1000.0F;
  lastControlMs_ = nowMs;

  if (!hasTarget(nowMs)) {
    stopTracking();
    return;
  }

  const float yawError = applyDeadband(horizontalError_);
  const float pitchError = applyDeadband(verticalError_);

  // Reverse either sign here if an axis moves away from the target.
  yaw_.moveBy(yawError * config::kYawGainDegPerSecond * elapsedSeconds);
  pitch_.moveBy(pitchError * config::kPitchGainDegPerSecond * elapsedSeconds);
}

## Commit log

2026-10-04 Add PlatformIO ESP32-S3 firmware starter
2026-10-05 Add camera-controlled EVT draft, CAD, wiring and teaching guide
    [fixture-plate.step, fixture-plate.stl, layout-draft.step]
2026-10-05 Add power-off translator, stop interlock and parametric mount drafts
    [camera-saddle-draft.step, camera-saddle-draft.stl, fixture-plate.step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]
2026-10-05 Draft moving carriers and verify sampled joint-frame geometry
    [carrier-fixture-plate.step, carrier-fixture-plate.stl, carrier-layout.step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]
2026-10-05 Preserve camera capture age and reject invalid frame metadata
2026-10-05 Reject ambiguous multi-region red marker frames
2026-10-05 Add source-checked visual carrier assembly review
2026-10-05 fix: require explicit camera selection after stream faults
    [main.cpp, test_camera_stream.cpp]
2026-10-05 Fix S3 PWM resolution and inhibit arming on timer setup failure
    [app_config.h, main.cpp, servo_axis.cpp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]
